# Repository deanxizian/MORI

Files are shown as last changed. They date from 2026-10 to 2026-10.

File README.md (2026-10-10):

# MORI

MORI 是一个两轮主动平衡机器人原型：两只轮驱舵机、头部偏航与俯仰两只舵机、圆形屏幕、真实摄像头及板载音频。

本仓库整理机械、硬件、软件、采购和验证资料。**当前为 PROTOTYPE / UNVALIDATED，未完成实物装配、上电和主动平衡验证，未制造放行。** 当前机械模型为 M1.55，已应用 C6 通道、CAM USB 朝右和用户批准的 R2 颈部装入修正，详见[本次更新](docs/M1_55_MODEL_UPDATE.md)。

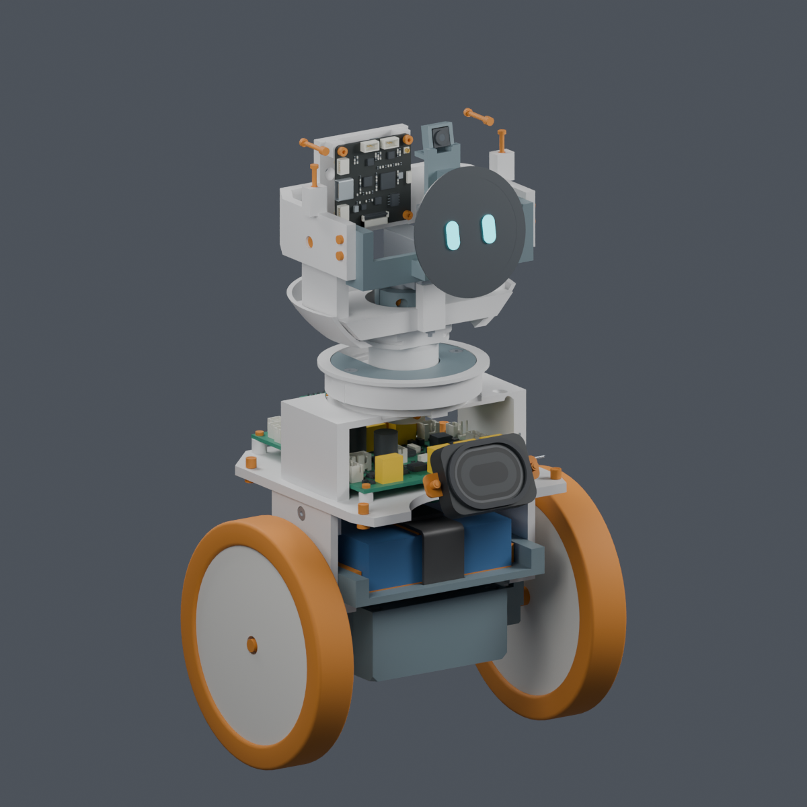
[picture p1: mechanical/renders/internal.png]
MORI 当前结构预览


首次归档的[拆分 PR 与审查修复](docs/REVIEW_STACK.md)已合并。历史与大批生成数据保留在不可变归档。

## 先看这些

| 要找的资料 | 入口 |
|---|---|
| 项目资料总索引 | [PROJECT_INDEX](docs/PROJECT_INDEX.md) |
| 当前版本与未完成事项 | [CURRENT_STATUS](docs/CURRENT_STATUS.md) |
| 到货前剩余工作与资料依赖 | [待补资料清单](docs/PREARRIVAL_BLOCKERS.md) · [未采用线束研究摘要](mechanical/studies/harness_M1_55_summary/index.html) |
| 从哪些厂家购买哪些产品 | [采购清单](mechanical/procurement/M1.52_按厂家采购清单_2026-10-06.md) · [已下单记录](mechanical/procurement/采购记录.md) |
| 机械模型、图册与装配视频 | [机械入口](mechanical/README.md) · [网页图册源文件](mechanical/index.html) · [装配视频](mechanical/animation/MORI_assembly.mp4) |
| 四块 PCB 的原生工程与接线 | [原生工程包与解压说明](hardware/v1_2/native_projects/README.md) · [P5R7 接线](hardware/v1_2/wiring_P5R7/README.md) |
| 网页、固件和模拟测试 | [软件说明](README_SOFTWARE_V1_2.md) · [原有验收记录](https://github.com/deanxizian/MORI/blob/48fe22aa75554c9d7bb237e2d2dcacca7f83dde1/reports/v1_2/acceptance.md) |
| 下载大文件、在本地打开图册 | [下载与归档说明](docs/GITHUB_ARCHIVE.md) |
| 历史版本和旧文件的适用范围 | [历史索引](docs/HISTORY.md) |

## 当前基线

当前资料整理日期：**2026-10-10**。规格为 [MORI_SPEC_V1_2.md](MORI_SPEC_V1_2.md)。

| 工作包 | 当前入口版本 | 说明 |
|---|---|---|
| 机械 | **V1.2-M1.55** | 主模型、电子细模和预览；当前 16 件机器人打印件，导出目录的 21 个 STL 还含其他试配文件 |
| 装配动画 | **V1.2-M1.55-A1** | 87.5 秒、22 步；裸打印件反力夹装入已修复，实际舵盘与完整带线装配仍未闭合 |
| 硬件合同 | **V1.2-H0.5-P5R7** | 运动板／后接口板 P5R7，电源板 P5R6，IMU 板 P5R4 |
| 软件 | **1.2.0-dev.1 历史交付记录** | 原验收日期 2026-09-22；不能据此声称已适配或验证后续 P5R7 硬件 |

硬件合同选择 WeAct STM32F412RET6 64Pin V1.1。2026-10-07 的审查修复已迁移默认编译目标并完成交叉编译，板级接通与实机验证仍未完成；详见[复核记录](docs/REVIEW_CLOSURE.md)。本次机械更新没有改动固件。

## 资料的有效范围

- 机械尺寸以 [config/geometry.json](config/geometry.json) 为当前唯一来源，安装契约为 [mechanical_interfaces.json](contracts/mechanical_interfaces.json)。单位 mm，+X 向右、+Y 向前、+Z 向上。
- 硬件选型以 [components.json](contracts/components.json) 为准；电气契约、原生 KiCad 板和正式交接各保留来源与版本。
- `mechanical/studies/` 同时包含已采用方案、未采用候选和失败试验。候选目录、截图或局部 PASS 不自动等于当前主模型。
- 根目录 `params.json`、`scripts/`、`models/`、`renders/`、`exports/` 属于 A0 历史。`hardware/v1/` 和旧软件台架记录也不是当前接线或尺寸依据。
- 几何检查、ERC／DRC、主机测试与仿真均不等于实物装配、热性能、材料强度、电池安全或平衡验证。

## 本地阅读

三个 Blender 工程采用 **Git LFS**；大型网格按需从不可变归档恢复，四套原生 KiCad 工程以 ZIP 保存完整文件，并保留可读的原理图与规则；工程包、视频、文档与源码使用普通 Git。克隆后先执行 `git lfs pull`，再按 [下载说明](docs/GITHUB_ARCHIVE.md)核对资产。GitHub 的 HTML 文件视图显示源代码；本地图册可这样打开：

```sh
python3 -m http.server 8000 --bind 127.0.0.1
```

浏览器打开 `http://127.0.0.1:8000/mechanical/index.html`；装配动画入口为 `/mechanical/animation/index.html`。这只启动静态资料服务，不启动控制程序。

旧软件 CI 配置保留在原始归档；这组资料 PR 没有新增自动构建或部署，也没有运行机器人或烧录固件。完整重建与历史对比的依赖边界见下载说明。

## 来源与许可

保留 [第三方通知](THIRD_PARTY_NOTICES.md)、[软件 V1.2 通知](software/THIRD_PARTY_V1_2.md)和 [机械来源说明](mechanical/THIRD_PARTY_NOTICES.md)。厂家文件与图片保留其原始来源和权利；公开仓库不改变第三方许可。本次没有为 MORI 自有内容另行指定开源许可证。

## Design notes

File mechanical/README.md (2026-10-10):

# MORI 当前机械资料

当前快照：V1.2-M1.55；装配动画：M1.55-A1。已采用 C6 通道、CAM USB 朝右和批准的 R2 颈部装入修正。相对 M1.54，只有 Pitch_Yoke 实体及其 STL 改变，其余 200 件原生零件和全部硬件位姿保持；不增加打印件或紧固件。主模型、电子细模、预览和动画已同步，详见[M1.55 更新](../docs/M1_55_MODEL_UPDATE.md)。完整线束未采用，PROTOTYPE / UNVALIDATED。

- [主模型](mori_v1_2.blend)、[电子细模](mori_electronics_detail.blend)、[动画工程](mori_assembly_animation.blend)：Git LFS。
- [21 个 STL](exports/)：含机器人本体打印件及其他试配文件，未制造放行。
- [视频](animation/MORI_assembly.mp4) · [视频页](animation/index.html) · [静态图册](index.html)。
- [构建与检查脚本](scripts/) · [几何源](../config/geometry.json)。
- [按厂家采购表](procurement/M1.52_按厂家采购清单_2026-10-06.md) · [已下单记录](procurement/采购记录.md) · [本次发布说明](../docs/M1_55_MODEL_UPDATE.md)。
- [未采用线束研究摘要](studies/harness_M1_55_summary/index.html) · [到货前待补资料](../docs/PREARRIVAL_BLOCKERS.md)。

直接打开当前 Blender 文件无需恢复历史数据。重新运行建模脚本前，应按 [归档说明](../docs/GITHUB_ARCHIVE.md)恢复源模型和生成网格，并准备原记录的 Blender／CAD Python 依赖。单个历史比较还可能依赖额外归档文件，不能跳过缺失项后声称检查通过。

头部最终传动配件、完整线束与实物验证仍未闭合，见 [当前状态](../docs/CURRENT_STATUS.md)。R2 裸打印件装入通过不代表实际舵盘或带线初装通过。

当前构建完成后运行 `python3 mechanical/scripts/report.py`，输出 `mechanical/current_report.html`。该命令校验当前输入与构建证据；不会用 M1.43 的报告模板覆盖当前版本，也不覆盖保留的图册。缺失或过期证据会返回非零退出码。

完整重建前先运行 `python3 tools/restore_archive_assets.py --group mechanical-build-inputs --group native-pcbs`，以及归档说明列出的厂家源输入，再运行 `python3 tools/restore_m1_55_evidence.py --group approval` 恢复 R2 比较输入。Blender Python 需要与其 ABI 匹配的 `manifold3d`；脚本记录实际安装版本。金属件导出直接使用 OCP（`cadquery-ocp`，本轮为 7.8.1.1），通过 `MORI_CAD_PYTHON=/path/to/python` 指定；缺失依赖时明确失败。`run_all.py --core` 完成当前构建、几何检查、渲染、STL/STEP 导出和报告刷新。R2 检查另保护了本地未发布的硬件候选快照；公开克隆没有这些快照时，完整来源保护重放会失败，不能跳过后声称全部检查已重现，详见[本次证据边界](../docs/M1_55_MODEL_UPDATE.md)。

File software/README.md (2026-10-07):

> **当前 MORI V1.2 入口：** [README_SOFTWARE_V1_2.md](../README_SOFTWARE_V1_2.md)。当前只开发网页，App 暂停。本页及原报告保留为HW-SW-0.4/A0台架记录，旧GPIO/电池阈值/PWM/CPR不适用V1.2。
> 固件源已原样迁移并增量适配到 `../firmware/motion/`，`firmware_work/firmware` 是兼容符号链接，没有第二份硬件固件。V1默认不初始化旧候选GPIO。

# MORI软件调试工程 SW-0.4

当前接口基准 **HW-SW-0.4 / 2026-09-21**，已依用户本次指令在现有工作副本上合并，模块台架候选，**PROTOTYPE / UNVALIDATED**。保留既有状态机、严格协议、模拟HAL、安装配置、表情/头轨迹和安全回归修复。没有连接、烧录或旋转真实设备；实物与自由平衡均 **NOT_TESTED**。

## 本次接口同步

轮电机候选改为Pololu #4863：48 CPR已含x4，精确减速比22³×23/(12×10³)，1:1候选皮带，979.616 counts/rev，Ø95轮每计数0.000304661522567m。运行时换算只定义于`mori_io.h`，设备INFO与模拟源共用配置；单边沿8帧测速、48边沿一电机转和元数据精度均有回归测试。GPIO、方向符号、IMU量程、保护阈值和默认安全门未改变。

编码器使用DEVKIT_5V供电，四条A/B经3.3V供电的SN74LVC14AD转换，禁止5V信号直入ESP32。USB前拔**整个J12逻辑降压线束，J14保持连接**；逻辑USB/外部5V互斥，禁Wi-Fi，含编码器预算<500mA。控制left对应Blender Wheel_R/Motor_R（X正）。VMAIN ADC不能覆盖可能被隔离的VM_MOTOR回灌尖峰，软件过压阈值保持8.65V。详细线序、钳位候选和限制见`docs/hw_sw_0_4.md`及调试手册。

本次接收的0.4快照23个成员均按manifest校验；基线在独立报告目录重新构建。最早从0.3解出的工作副本没有被覆盖，`baseline_integrity.json`保留原始追溯。旧发布报告归档到`reports/pre_hw04_merge/`；24个旧SIMULATED文件保留原内容和元数据，0.4演示另生成`SIMULATED_hw04_*`。此前接口兼容性FAIL的历史记录保留，其变更依据与解决结果见ICR-012、`reports/hw04_adoption.json`和当前`reports/final_validation.json`。

## 可运行入口

在`/Users/dean/Documents/MORI`执行：

```sh
# C主机回归、安全状态机、模拟HAL、严格协议及电机适配器（ASan + UBSan）
bash software/scripts/test_host.sh
# Python协议、采集/回放、模拟PTY串口、离线方向核验
python3 -m unittest discover -s software/tests -p 'test_*.py' -v
# ESP-IDF v5.5.2安全门关闭的默认配置构建，只build、不flash
bash software/scripts/idf_build.sh
# 校验仓库内附带的0.3/0.4 ZIP快照，不能代替当前代码或实机验证
python3 software/scripts/verify_delivery.py --archives-only
# 旧交付的完整审计需要另行恢复历史证据和当时构建产物；当前源文件已演进，可能报告差异
python3 tools/restore_archive_assets.py --group legacy-software-verification --group legacy-helpers
python3 software/scripts/verify_delivery.py
# 严格检查与本次已采纳0.4上游一致；不代表实物获准上电
python3 software/scripts/verify_delivery.py --require-current-handoff

# 无硬件演示：输出文件名必须含SIMULATED；换用新的文件名避免覆盖
bash software/scripts/build_simulator.sh
python3 software/tools/mori_cli.py simulate --frames 1000 --scenario estop --output software/reports/SIMULATED_demo_new.csv
python3 software/tools/mori_cli.py replay software/reports/SIMULATED_demo_new.csv
python3 software/tools/mori_cli.py validate 'move 0.02 0'
python3 software/tools/mori_cli.py fault 11
python3 software/tools/check_control_signs.py --output software/reports/SIMULATED_direction_new.json
software/reports/bin/SIMULATED_face 360 software/reports/SIMULATED_face_360_new.ppm
```

主机工具只用Python标准库和本地C编译器；串口使用POSIX termios（本次只在模拟PTY验证）。设备端仍用项目原dependencies.lock：ESP-IDF5.5.2、GC9A01 2.0.3、cmake_utilities0.5.3，未升级。`idf_build.sh`检查本地IDF tag严格等于v5.5.2。工作副本主机脚本指向software的安全包装；0.4上游基线另在reports中构建和运行，不执行hardware目录脚本。

真实串口须由用户以后明确提供端口再操作。采集只自动发info查询；`send --command`只发送显式提供的命令，支持多次`--command`完成有限台架脉冲。绝不自动发arm、confirm_signs、gains或ack，不自动重试/重连。ACK丢失是UNKNOWN，不推断执行失败，也不自动disarm。

## 目录与证据

- `firmware_work/firmware/`：以0.3ZIP为初始来源、已选择性合并0.4接口的独立ESP-IDF工程；portable `mori_core`、真实HAL、圆屏驱动。
- `firmware_work/pinmap.csv`及`wiring.csv`：0.4交接镜像，只读对照；GPIO未改。
- `tests/`：注入式时钟/传感器/执行器HAL、原问题回归、IDF LEDC契约stub和协议/工具测试。任意测试增益仅用于分支验证，不是实机调参数据。
- `tools/`：MORI/1串口采集、CSV回放、SIMULATED设备与表情渲染、方向/安装矩阵检查。
- `docs/debug_manual.md`：断电到低速运动的八阶段实物调试流程；`protocol.md`、`realtime.md`、`direction_checks.md`给出接口和测量口径。
- `config/`：实物记录及安装矩阵模板；未填项均NOT_TESTED/null。
- `interface_change_requests.md`：ICR-001..012，ICR-001旧电机提案已废止；ICR-012记录本次授权合并，其余安全/协议修复保留。
- `reports/`：真实命令/退出码/日志、快照与最终文件/镜像SHA、模拟CSV/JSONL/元数据；Git仓库不存在，Git状态NOT_APPLICABLE。

## 本次真实验证结果

- 修改后的C测试：2406条断言（163原始核心 + 2211模拟HAL/状态/协议/UI + 22电机适配器 + 10默认关门）及4项行为回归PASS，开启ASan/UBSan。
- Python：24项PASS，含5项HW-SW-0.4计数/8帧测速/元数据/接线验收，以及串口模拟PTY和严格协议/回放测试。
- ESP-IDF v5.5.2：默认关门、无屏、门内代码编译覆盖3种构建PASS；另在独立目录复现0.4上游基线构建及163断言PASS。
- 0.4模拟急停1000帧、复位400帧采集/回放PASS；旧版回放保留1204.44元数据，24个旧模拟文件哈希未变。
- 先前FAIL记录保留：0.4接口前置回归、主机测试中的float/double比较警告（已修正），以及构建路径纠正记录。当前结论/命令/退出码见`reports/final_validation.json`，源文件/产物SHA见`reports/delivery_manifest.json`。实物全部NOT_TESTED。

```sh
# 验证已生成的新旧版本模拟记录，无设备IO
python3 software/scripts/verify_hw04_recordings.py
# 读取0.4采集结果；不会将CSV重发为设备命令
python3 software/tools/mori_cli.py replay software/reports/SIMULATED_hw04_estop.csv
```

## 验证范围

| 功能 | 功能实现 | 单元/模拟或主机构建 | 实物验证 |
|---|---|---|---|
| HW-SW-0.4快照、接口同步、基线构建和163断言复现 | PASS | PASS | NOT_TESTED |
| DISARMED→CALIBRATING→READY→BENCH/BALANCE、锁存FAULT | PASS | PASS | NOT_TESTED |
| 默认关门/0增益、显式解锁、台架限幅/不续期、stop/断联语义 | PASS | PASS | NOT_TESTED |
| 故障注入：IMU旧/缺样、编码器跳变/冻结、ADC/NTC、过流/温/压、倾倒、饱和、nFAULT/急停、超时/溢出/复位 | PASS | PASS | NOT_TESTED |
| 严格MORI/1、ACK/REJECT、时间戳、回放、分位数/丢弃计数 | PASS | PASS | NOT_TESTED |
| 矩阵/正反号配置、速度外环→倾角→唯一公共姿态力矩 | PASS | PASS（符号关系，不是稳定性证明） | NOT_TESTED |
| 无屏/可变分辨率/圆形裁切/GC9A01 SPI后端 | PASS | PASS（编译/渲染） | NOT_TESTED |
| 头部限加速度轨迹与低优先级任务、未核验无PWM | PASS | PASS | NOT_TESTED |
| 1800us预算/健康帧心跳/分段测量钩子 | PASS | PASS（模拟超时与门控） | NOT_TESTED |
| 装机适配、真实电气/热/稳态/自由平衡/续航 | NOT_TESTED | NOT_APPLICABLE | NOT_TESTED |

本轮基线问题先记录FAIL，再修复并重跑：重复时间戳校准、首个故障被覆盖、READY失健康不锁存、额外命令字段被接受、提示词与快照的轮计数比例冲突、200ms台架截止晚一个帧、IDF同步LEDC更新缺少fade service初始化、BENCH输出覆盖低电告警。最终验证结果见`reports/final_validation.json`；历史FAIL日志保留用于复现，不伪装成硬件失败或抹除。

安全默认：POWER_STAGE_VERIFIED、ENABLE_BALANCE、HEAD_VERIFIED、AXES_VERIFIED均n，kp/kd/kv/ki全0。左右电机/编码器符号候选保持+1/−1；安装矩阵identity未验证。新增/修改接口必须走变更单。电池阈值保持6.8/6.6/6.0V及过压8.65V，不能代替BMS/保险/充电器/急停。屏幕240×240/Ø32.4mm仅编译与台架后端，最终Ø60屏仍未定。

## 追溯与再次构建

```sh
# 每次使用新的name，工具拒绝覆盖已有记录
python3 software/scripts/run_recorded.py --name local_build_01 -- bash software/scripts/idf_build.sh
python3 software/scripts/run_recorded.py --name SIMULATED_local_tests_01 -- bash software/scripts/test_host.sh
# 单独复现已封存HW-SW-0.4基线（报告区，不覆盖工作副本）
bash software/scripts/reproduce_hw04_baseline.sh
# 修改源文件后先完成验证，再更新交付哈希；不可用更新哈希掩盖检查失败
python3 software/scripts/fingerprint.py
python3 software/scripts/verify_delivery.py
```

`run_recorded.py`记录argv、cwd、UTC、返回码、完整输出及SHA；新记录也含运行前输入文件SHA。`baseline_integrity.json`保留最初0.3ZIP21个成员；`hw04_adoption.json`记录0.4ZIP23个成员、源文件和旧模拟文件SHA。默认镜像在`firmware_work/firmware/build/`。`build_variants.sh`只作无屏和门内代码编译覆盖；其`DO_NOT_FLASH_gated_coverage`镜像不具备实物签字，禁止用于台架出力。IDF自动输出的flash建议没有执行。

仍需硬件决定/提供：R矩阵与四个方向符号签字、真实皮带齿数/轮周长、功率安全链与母线回灌响应、最终电池/保护/充电路径、显示面板及总线、头中心/方向/行程/线缆、板卡和IMU外置或机械重排。仍需实测：所有通电/旋转/关断波形、传感器标定、时序最大值、负载干扰、扭矩/摩擦/惯量/热裕量及防摔下闭环表现。未完成这些项目，不宣称机器人已经能平衡。

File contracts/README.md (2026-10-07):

> 硬件候选已更新为 **V1.2-H0.2-P1**：[器件真值](components.json)、[电气真值](electrical_interfaces.json)。板间候选1Mbps，运动GPIO/DMA已按F412载板分配；实物资格未释放。MORI/2帧及软件profile仍由软件维护，本次未改协议源。

> S288专用CRC与下述CRC32不是同一算法。F413软件需按[硬件ADR](../reports/decisions/ADR-HW-V1_2-002.md)新增F412适配，不沿用A0的ESP32/PWM/2S接线。软件文档下文中“尚无引脚”的历史边界由电气契约更新，实际实时驱动接入仍归软件任务。

# MORI/2 软件契约 1.0

`command_spec.json` 是命令目录、参数类型、数值范围、权限、最长有效期的唯一软件定义。
`protocol.py` / `protocol.ts` 严格校验，`generate.py` 生成 JSON Schema 与嵌入式命令编号/数值校验；
`test_vectors.json` 在 Python 与 TS 跑同一批有效/无效样本。C 的数值子集另外做交叉 CRC 与属性测试。
机械值以 `mechanical_interfaces.json` 与 `../config/geometry.json` 为准，本目录软件协议不重定义孔位/器件尺寸。

## 命令与仲裁

一个消息只包含以下字段，额外/缺少字段、NaN/Inf、布尔冒充数字、范围溢出均拒绝。
原始 JSON 最大 4096 UTF-8 字节；后端额外拒绝重复 JSON 键、截断、非法 Unicode/递归对象。

```json
{"protocol":"MORI/2","device_id":"mori-sim-01","session_id":"从状态取得","command_id":"每个意图唯一ID","client_id":"配对返回ID","source":"console","permissions":["control"],"type":"SET_VELOCITY","params":{"v_m_s":0.1,"yaw_rad_s":0},"sequence":1,"sent_at_ms":100,"basis_device_ms":100,"valid_for_ms":300}
```

上例 ID 说明是占位文字，实际 ID 必须 `[a-zA-Z0-9_-]{1,64}`；不要照抄它发送。
`sent_at_ms` 只用于发送端日志，不用于跨机器时钟相减。`basis_device_ms` 必须回显最近状态的设备单调时钟；
设备按 `now - basis` 检查期限。因此旧状态不会因为网络重发获得新的300ms。
采集帧另带 frame_id、captured_ms、processed_ms、采集时头角/机身姿态；返回结果须匹配本机帧登记表。

命令目录含读取、显式解锁/人工维护、正常停止、故障禁驱、SI 速度、有限位移/转角、双轴头部、
表情、相机三模式、选目标、跟随/巡游/主动动作、取消、持久记忆 CRUD/导出/开关、音量、会话、按钮和唤醒配置。
详细参数和枚举以目录为准。ACK 表达明确结果状态，不等同动作完成：
ACCEPTED → RUNNING → COMPLETED / CANCELLED / EXPIRED / FAULT；格式/权限/门禁失败为 REJECTED。
有限动作的终态也发布在遥测事件中，控制台据此更新日志。

- 凭证权限在服务端决定；请求中的 permissions 只是所需权限，不能提升自己权限。
- 取得控制权须明确操作者看护；活跃租约由一个客户端持有，另一个会收到 CONTROL_OWNED。
- UI 前台每100ms续租，设备期限最多300ms；pointerup/cancel、blur、hidden、App inactive、断线停止续租。
- 断线撤销非零目标，健康平衡保持；重连不重放动作、不自动取得控制权或解锁。
- STOP_MOTION、FAULT_STOP 具有更高优先级，可用较旧序号停止，但仍需有效会话/权限/期限。
- 相同 command_id 不再次执行、也不续租；不同客户端撞 ID 被拒绝。每会话每客户端 sequence 单调。
- 交互/相机配置/记忆的认证独立于运动租约。头部、轮移动、解锁和自主模式必须持有运动租约。
- CANCEL 只取消当前匹配的动作，拒绝无匹配 ID；更换运动目标取消原目标。复位换 session 并禁驱。
- 模型/VLM/记忆内容是数据，没有 shell、原始 PWM、参数修改或公开相机工具。

## 两 MCU 二进制子契约

`wire.c/h` 与 `wire.py`：小端，`A5 5A | version=2:u8 | kind:u8 | payload_len:u16 |
sequence:u32 | MCU_boot_session:u64 | command_id:u64 | payload | CRC32:u32`。
CRC32 覆盖此前全部字节（IEEE/与 zlib.crc32 一致），最大 payload128、总帧158字节；不完整帧50ms丢弃。
版本/长度/零会话/零序号/零ID/CRC错误丢弃且计数。这里是本地电气损坏检测，**不是身份认证**。

运动子集 payload 固定前缀：`basis_device_ms:u64 + valid_for_ms:u16`，后接参数。
无参：READ_STATUS/HEARTBEAT/STOP_MOTION/RELEASE_CONTROL/FAULT_STOP；最后一个使用通用本地故障码。
布尔1字节且必须为1：CLAIM_CONTROL(监督确认)、ARM(本地确认)、DISARM/ACK_FAULT/ENTER_MAINTENANCE(支撑确认)。
两 float32 SI：SET_VELOCITY(v,yaw_rate)、HEAD_TARGET(yaw,pitch)。不支持的类型/长度明确 REJECTED。
网络端的人类原因/维护细节不会被任意透传为执行器字节。C 接收器把 legacy `MC_MOVE.b` 看作差动PWM，
故在未提供经过测量的 yaw-rate 控制器前拒绝非零 rad/s 请求，绝不按原增益直连。

`mori_v1` 已有可注入时间的解析/租约/禁驱/两轴轨迹测试；串口引脚、波特率、隔离、安全线、
完整状态回包与硬件四执行器 adapter 尚受 V1 硬件契约阻挡，默认固件不初始化任何候选 GPIO。
这不是可直接连接任意主控的接口承诺。上层自主状态机在同协议模拟器完整执行，实机门为 BLOCKED。

## 旧协议

MORI/1 和 HW-SW-0.4/0.5 台架 CSV 继续由 `software/tools/` 支持，原始日志不重标为 V1。
旧候选 GPIO、符号、979.616 counts/rev、母线阈值仅属于显式 A0.5 bench profile。
两协议不自动互转，不自动发 arm、confirm_signs、gains、ack。更改见软件接口变更单。

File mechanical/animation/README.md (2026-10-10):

# MORI 装配动画

MORI 装配动画 / V1.2-M1.55-A1

当前场景：MORI_Assembly_Animation。空格播放，Shift+左方向键回到开头。
总长 87.50 秒，24 fps，共 2100 帧。
时间轴的 22 个中文标记同时切换对应相机。每个零件保留独立物体与关键帧。
在 Outliner 按步骤展开集合；选零件，在 Dope Sheet / Graph Editor 调整时间。
原始 MORI_V1_Assembly 场景保留真实总装与运动轴，可切回检查尺寸。

身体改为前后两片外壳。承重桥在身体外壳未装时单独下放、前移并锁紧。
前壳喇叭和后壳接口板在台面分别预装；内部总成完成后，前壳沿-Y、后壳沿+Y合入。
底部两组一体插舌定位，四枚原框架螺钉经底部工具孔锁紧；旧拼缝螺钉和嵌件取消。
每片模块含原生附件的名义平移路径各检查275个位置，不含独立插头包络。
保存后的动画可另以半帧抽样；该项需单独的动画回读记录。
完整软线长度、变形和带线合壳仍未完成，动画未把静态导线示意当作装配证明。
双舵机先在离机座上锁紧；Pitch先在X+30mm处下放，再向左平移到位。
C压板先从侧面套到转动座，随驱动座一起下放。随后转动座转60°，
从上方锁两枚M3×8后回正，再安装俯仰头部。固定压板不随Yaw转动。
M1.49采用6806ZZ轴承（30×42×7mm）；压板配对孔位为X±26.2mm，
外径60.4mm。颈部11条局部导线空间检查不代表完整线束已完成。
拆卸需先移除俯仰头部，松开压板和反力连接后上提，不是整头快拆。
其他位移、台面预装与镜头切换仅作装配讲解。全动画的连续扫掠、人手／夹具、
完整软线束、紧固扭矩与真实零件公差仍未验证。头部舵盘／短轴仍未定型。
橙色表示未完整确认的部件；没有缩放采购件或改变候选 STL。

降压器区分：第6步的外置模块是轮驱9V（D36V50F9）和头部6V（D24V22F6）。
第7步电源板上的U60/U70已集成运动5V和CAM 5V；没有另装两块外置5V模块。
本视频采用V1.2-M1.55主模型，运动基板与后接口板已更新为P5R7；电源P5R6、IMU P5R4。
M1.54将CAM USB转向机器人右侧+X；CAM端相机FPC朝左-X，屏幕FPC朝下-Z。
M1.52仅把两枚现有反力连接试配螺母绕原孔轴转正30°，与六角槽方向一致。
M1.53将固定偏航桥左侧穿线口外边缘加宽0.8mm；轴承座和五金位置保持。
M1.55 R2 已应用裸反力轴从下方装入的步骤；保存后路径须通过独立回读。实发舵盘与最终锁紧叠层仍待到货核对。
槽口/触点仅为示意，真实插深、补强片和接触面仍未确认；完整线束尚未应用。
WeAct元件面朝上、排针朝下；先放三组排母，再插入核心板与E直排针候选。
E排针与原厂STEP孔径资料矛盾仍为BLOCKED，11.04mm是候选叠层，不能据动画确认实物配合或下单。

重新生成并回读验证（先成功生成当前主模型；R2 研究脚本可从 validation 资料包恢复）：

```sh
python mechanical/studies/reaction_clamp_R2_adoption/run_deliverables.py
```

[当前采用记录](../../docs/M1_55_MODEL_UPDATE.md)

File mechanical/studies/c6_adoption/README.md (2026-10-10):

> 这是 M1.53 采用时的历史检查记录；当前主模型已更新到 M1.54。当前结果见[发布说明](../../../docs/M1_54_MODEL_UPDATE.md)。

# C6 已应用 · V1.2-M1.53

用户确认后，将固定偏航桥 Yaw_Base 既有左侧穿线口外边缘向外加宽 0.8 mm。原外半径 11.7 mm → 12.5 mm，移除约 22.0474 mm³；不增加零件或紧固件。主模型、电子细模、21 个 STL、预览和 M1.53-A1 装配工程／完整视频已同步。

- 与审查后的 M1.52 原生几何逐件比较：只改变 Yaw_Base，其余 200 件保持。轴承座、孔轴、紧固件及所有硬件变换保持。
- 21 个导出件均通过闭合拓扑和 Blender STL 回导检查。机器人本体仍为 16 件打印件，其余是既有试配／支撑等输出。
- 九条历史下部线路对当前 201 个原生实体：1404 次分组有限姿态检查，均满足 0.3 mm 名义净距下界；采用前的槽口有 52 次不足。最近的实际查询样本下界约 0.3996 mm，但它不是所有路线的全局最小值。
- 身体前后模块各 275 个平移位置重新检查；保存后的动画回读还检查了分壳、防脱与舵机台架预装。原生实体之外的对插分配包络、软线和人手操作未据此放行。
- 全部既有硬件源文件与硬件合同哈希保持。该检查发生在本次 PR 发布之前。

完整线束仍为 BLOCKED：恒定材料长度、上端固定／应力释放、FFC／FPC 及带线闭壳等尚未完成。九条候选线路、滑动导线约束和回弯固定未随槽口一并采用。原有 WeAct 等资料问题仍单独保留，局部结果不是整机装配完成。PA12 配合、强度和疲劳 NOT_TESTED；manufacturing_release=false。

数值清理：新切口转存 float32 前以 1e-7 mm 简化容差去除四个退化三角形；与未简化实体的对称差约 1.09e-7 mm³。独立批准参考与保存后实体的差异另记于检查报告；这不是打印配合公差。升版时也保留了已审查的头前壳碎片清理。失败尝试日志保存在 attempt1/、attempt2/、attempt3/，没有跳过失败项。

[剖面对比](section_comparison.png) · [主模型](../../mori_v1_2.blend) · [Yaw_Base STL](../../exports/stl/Yaw_Base.stl) · [装配视频](../../animation/index.html) · [局部检查](review.json) · [范围检查](../../reports/neck_entry_relief_validation.json) · [当前整机检查](../../current_report.html)

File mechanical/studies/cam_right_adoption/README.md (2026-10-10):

# CAM USB 朝右已应用 · V1.2-M1.54

2026-10-08 用户批准“行，试试看usb朝右吧”。CAM 整板及板载两颗麦克风绕不变的板中心、世界 Y 轴转 -90°，USB 口朝机器人右侧 +X。正面对板观察时，机器人右侧位于画面左边。

相对 M1.53：只转动 CAM_Mainboard / Onboard_MIC_L / Onboard_MIC_R，另外 198 件的原生实体与可见网格逐件保持；所有 21 个 STL 文件的 SHA256 完全相同。板框、中心、32.6 mm 四孔轴集合、原固定座、螺钉、相机模组与 LCD 不变，不增加打印件。全部既有硬件源文件和 components.json 保持。

当前主模型、电子细模、预览和 M1.54-A1 装配动画／完整 MP4 已同步。视频仍为 22 步、85.75 秒、1280×720、24 fps。当前 core 检查为 26 PASS / 0 FAIL / 9 NOT_TESTED / 11 BLOCKED，后两类没有被此次局部通过覆盖。

## 已检查的范围

- 当前 201 个原生零件的静态、130 个组合头姿态、拓扑、光学和主要进出路径检查；原 WeAct 源模型孔针问题仍单列 BLOCKED。
- 10×5×12、10×5×16、11.2×6.7×17.5 mm 三种 USB 本体**设计预留**，130 个姿态下达到 0.3 mm 名义净距；不是已采购完整插头或实测插合尺寸。
- 四枚原 CAM 螺钉的 12 条工具／螺钉扫掠，及下述连续纯平移安装路径。动画另按半帧读取了 471 个可见 CAM 零件姿态，没有检出与当时可见原生零件的穿插。
- 两个板载麦克风从左右排列转为上下排列，原 L/R 名称保留源通道身份。共享头腔到既有声孔的名义空隙探针通过；未增加声学导管或新孔。声音定位、声学和 RF 性能仍需实测。

## 安装顺序

显示架和头壳后装，CAM 四枚螺钉尚未锁紧：板卡向前 +Y 错开 2 mm 从上方下放；离最终位置尚高 8 mm 时从右侧 +X 预接 USB；再下降 8 mm、向后贴回 2 mm，锁原来的四枚 DIN912 M2×5。动画展示该板卡路径；未添加虚构的成品 USB 插头。

## 走线交接

CAM 侧相机 FPC 出口 +Z → -X；屏幕 FPC 出口 -X → -Z；LCD 和相机模组一端保持。旧 M1.53 上端走线与长度结果只对旧方向成立，不能直接用作当前路线或供应商裁线图。信号、电源、喇叭上端及 FPC/FFC 必须重新组织并联合复核。此前下部线路也未随本次转向被自动放行。

完整插头／尾线型号、CC 源端、真实插合深度、排线触点面／长度、应力释放、带线闭壳和舵盘最终叠层仍未完成。没有扩大此次改动范围。全部模型依旧 PROTOTYPE / UNVALIDATED，physical_validation=NOT_TESTED，full_harness=BLOCKED，manufacturing_release=false。

[当前预览](index.html) · [主模型](../../mori_v1_2.blend) · [视频](../../animation/index.html) · [范围检查](../../reports/cam_orientation_validation.json) · [接口检查](../../reports/cam_right_service_validation.json) · [实际命令](commands.json)

2026-10-08 PR 同步复核：构建与全部衍生文件已按当前代码重新生成。动画回读先刷新隐藏验证集合，避免屏幕碰撞体使用旧矩阵；完整命令及日志见[执行证据包](execution_evidence.zip)，发布结果见[交付复核](../../../docs/review_evidence/M1_54_publication.json)。

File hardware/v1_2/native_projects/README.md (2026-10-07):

# 当前原生 KiCad 工程

四套完整工程按原生文件打包，来源为固定提交 `48fe22aa75554c9d7bb237e2d2dcacca7f83dde1`。运动／后接口 P5R7、电源 P5R6、IMU P5R4；没有改变尺寸、走线、符号或封装，也不代表制造放行。

| 工程 | 完整文件包 |
|---|---|
| 运动载板 P5R7 | [MORI_motion_P5R7.zip](MORI_motion_P5R7.zip) |
| 电源板 P5R6 | [MORI_power_P5R6.zip](MORI_power_P5R6.zip) |
| IMU 板 P5R4 | [MORI_imu_P5R4.zip](MORI_imu_P5R4.zip) |
| 后接口板 P5R7 | [MORI_rear_P5R7.zip](MORI_rear_P5R7.zip) |

原理图、设计规则、项目配置、接线表和说明仍在 `../kicad/` 以原生文本提供。PCB 与封装的完整序列化内容位于上述 ZIP；它们的行数超过 GitHub diff 上限，Git 属性不能阻止该接口展开这些文本。ZIP 使用普通 Git，不使用 LFS。每个包包含该工程的全部本地文件和配套库，供解压后直接在 KiCad 中检查。

在仓库根目录执行以下命令，`-n` 保留已有文件：

```sh
unzip -n hardware/v1_2/native_projects/MORI_motion_P5R7.zip -d .
unzip -n hardware/v1_2/native_projects/MORI_power_P5R6.zip -d .
unzip -n hardware/v1_2/native_projects/MORI_imu_P5R4.zip -d .
unzip -n hardware/v1_2/native_projects/MORI_rear_P5R7.zip -d .
```

然后从 `hardware/v1_2/kicad/MORI_*/` 打开对应 `.kicad_pro`。ZIP 内已带完整的仓库相对路径；无需重新缩放或移动 PCB。若本地已有修改，先保留并自行比较，不要覆盖。

[manifest.json](manifest.json) 记录每个 ZIP 及全部 242 个原始文件的 SHA256。2026-10-07 仅更新 connectivity/layout_notes/rule_mapping 的元数据；PCB、原理图、规则和配套库字节与原始归档一致。位置从包内实际 PCB 重新提取；这不是重新布线或制造验证。完整历史、旧方案和硬件验证记录仍在原始归档，不因本次打包获得重新验证。

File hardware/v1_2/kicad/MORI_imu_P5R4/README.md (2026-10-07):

# MORI_imu_P5R4

V1.2-H0.5-P5R4 / PROTOTYPE / 实物 NOT_TESTED。

本版保留 P5 电路、元件和针号；修改摆位、局部布线、IMU 专用 Paste 与轴向丝印。详见 [审查处理记录](../../layout_P5R4/README.md)。

外形与安装接口不变。PCB 不是制造释放文件；没有台架、ESD、温升或整机装配合格声明。

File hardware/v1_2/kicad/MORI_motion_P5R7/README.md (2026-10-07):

# MORI motion P5R7 — WeAct 插合修正原型

WeAct 元件面朝上，A–E 全部排针从核心板背面向下；载板 A–D 孔位与所有针号/网络分配保持。E 的 8 个孔相对 P5R6 整体 X+2.54 mm，Y 不变；新版项目使用独立修正版封装。载板仍只连接 E7/NRST，E 其余孔未接入载板电路。无需另接复位飞线。

|孔|原生 X mm|原生 Y mm|核心板信号|载板连接|
|---|---:|---:|---|---|
|E1|34.93|19.28|GND|NC|
|E2|37.47|19.28|GND|NC|
|E3|34.93|21.82|PA10|NC|
|E4|37.47|21.82|PA14/SWCLK|NC|
|E5|34.93|24.36|PA9|NC|
|E6|37.47|24.36|PA13/SWDIO|NC|
|E7|34.93|26.90|NRST|NRST → D1.1|
|E8|37.47|26.90|3V3|NC|

排母候选为 Würth 61303021821×2、61300821821×1；E 向下直针候选为 61300821121。排母本体高8.5 mm、焊脚长3.1 mm来自厂家图；完整插合高度、接触插深与保持力未验证。核心板的原厂 STEP 含 E 弯针，不能只旋转整个模型就当作上述装配。机械需替换排针装配姿态，并复核核心板上方空间、上下焊脚、维护/插拔路径。优先采购未焊针版本或要求按确认方向装配；不要把已焊弯针版本当作直接插合件。

70×35 mm 板框和安装孔保持。R19 从 (33,16) mm、−90° 改为 (32,16.575) mm、0°；R9 保持方向，下移3.25 mm至 (45,17) mm，打开中部走线/换层通道；其余器件位置保持。E 排母的实际本体投影另设两面布线约束，只有 E7 自身的直向逃线通道；没有 GND/电源的通用豁免。相关复位、反馈、按键、状态和 IMU 信号局部重布；另按实际 A–D 排母投影调整保留的 S288 总线及采样信号，滤波元件、接口功能和供电拓扑保持；新线0.20 mm，新过孔0.80/0.30 mm。原 P5R6 和原设计规则完整保留；新增规则限制 E 和 A–D 排母下的非自身走线；自身引脚逃线另作逐条复核。

PROTOTYPE / 实物 NOT_TESTED。完整原生检查、局部走线审查、68针位置表及新裸板 STEP 见 [本次交接记录](../../reviews/weact_E_J3_20260930/README.md)。机械空间仍需按正确朝向重新集成验证，没有下单或生产释放。

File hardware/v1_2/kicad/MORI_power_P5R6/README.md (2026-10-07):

# MORI_power_P5R6

V1.2-H0.5-P5R6 / PROTOTYPE / 实物 NOT_TESTED。

本版保留 P5 电路、元件和针号；运动板修正 BAT54H 焊盘；电源板缩短自举回路、并联 SW 过孔及消除 M5_EN 直角；电源/后板补充实际接口丝印。IMU 保留 P5R4。详见 [审查处理记录](../../layout_P5R6/README.md)。

外形与安装接口不变。PCB 不是制造释放文件；没有台架、ESD、温升或整机装配合格声明。

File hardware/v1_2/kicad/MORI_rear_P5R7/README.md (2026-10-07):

# MORI rear P5R7 — J3 装配修正原型

J3 保留 JST B4B-PH-K-S(LF)(SN) / PHR-4 / SPH-002T-P0.5S，改为 B.Cu 安装、180°，向下插拔。1 号孔为原生板坐标 (14.45,21.20) mm，孔排整体 Y+1.70 mm。原生顶视图从左到右为 4、3、2、1；各编号对应的网络和线束功能不变。

|针|网络|对端|
|---|---|---|
|1|MASTER_RETURN|电源板 J19.1|
|2|GND|电源板 J19.2|
|3|LOOP_3V3|运动板 J8.1|
|4|CLR_N|运动板 J8.2|

板框仍为原生 24×25×1.6 mm；安装孔、其余器件坐标、原理图拓扑均保持。P5R6 文件完整保留。不要在旧 P5R6 板上仅把插座翻面；P5R7 已调整编号孔位的网络连接。

三根互锁信号局部重布；0.20 mm 线宽、0.80/0.30 mm 新增过孔。J3 的塑料本体投影按 JST 图中 9.9×4.5 mm 确定，不把 Fab 层外侧的 1 脚 L 形标记算入实体；原有逐引脚逃线通道保留，无新增 DRC 忽略。

PROTOTYPE / NOT_TESTED。检查、几何局限和带哈希交接见 hardware/v1_2/reviews/weact_E_J3_20260930/README.md。SW1 电路本次保留；整机物理断电/急停实现另需闭合。没有下单或生产验证声明。

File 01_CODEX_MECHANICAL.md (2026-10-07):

# 提示词 1｜MORI V1.2 外观优化、内部结构与 Blender 装配

请实际改进并制作 MORI 的 Blender 工程。目标是“简洁好看、真实可装配、方便维护”，不是再出概念海报，也不是只把旧的丑模型换灯光。

## 0. 先读取与执行

先读本包 `MORI_SPEC_V1_2.md`、`AGENTS_MORI_TEMPLATE.md`、`04_HANDOFF_AND_ACCEPTANCE.md`、`REFERENCES.md`，再读现有仓库AGENTS、Blender模型/脚本、硬件BOM和共享接口。

检查Blender/Python/已有MCP。以Blender+bpy脚本为主，可用MCP辅助，不把MCP当开工前提。
保留已有可用零件与无关文件，先给一个简短实施计划，再实际改模、运行、检查。
没有.blend时按规格生成；没有Blender执行环境时交付可运行脚本与阻塞说明，不能伪造渲染或检查通过。

任务结果写入 `mechanical/`；拥有 `config/geometry.json`、`contracts/mechanical_interfaces.json`。只读取硬件任务拥有的 `contracts/components.json`，新增需求用ADR协商。
已有同用途参数文件时迁移/兼容，不能新旧脚本各读一份相互矛盾的参数。

## 1. 紧凑需求摘要

- 正常高度≤300mm；暖白圆润头身、圆形黑脸、仅双眼、隐藏双轴头、两只纯色车轮；不加轮毂灯环。
- 四电机：S288轮驱×2、SCS0009头部×2。无运行第三轮。
- 交互为微雪CAM-OV3660 SKU33700、1.85圆屏SKU35079、板载双麦和身体内扬声器。
- 运动为STM32小板+身体IMU；3S候选电池、电源板、USB-C充电口和至少一个实体功能按钮。
- 预算≤1000元尚未验证。采用FDM能做的分件、现成紧固件和平面面罩，不要求昂贵曲面玻璃、整件金属加工或喷涂才能成立。
- 用户已允许有限偏离正球形；不要因旧提示词而坚持把头/body切成不协调的球形方盒。

## 2. 先解决外形，不把结构孔洞到处摆出来

从当前实渲染定位问题，至少检查：

1. **身体轮廓**：正视图不应因左右过深平切而变成直侧板箱体。保留肩部到腹部的连续圆润收分，不用巨大平圆片/夸张轮眉盖住轮位。
2. **头部轮廓**：侧面不再用过大的整块切平让头看起来像戴平面头盔；圆屏窗口为局部需求，周围球面/柔和过渡保持自然。
3. **脸部比例**：显示有效区域45.68mm量级，以原厂图复核；面罩可更大但不能整块都画成能发光的屏幕。摄像头在有效区外的真实透光窗，优先融入黑色面罩，不增加一个巨大的额头洞。
4. **轮子**：适度内收，纯暖白轮盖+深灰胎；不外露长轴，不让轮胎卡进壳体，不因隐藏轴承造成不可拆。
5. **头身连接**：隐藏短转盘/支架，控制中立与俯仰时的缝隙；不是把完整头球与实心身体顶板互相穿模。
6. **细节**：分件线、按钮、USB-C、声孔分组布置。正面不堆螺钉、灯条和随意散落的小孔；不让分件缝穿过喇叭孔阵列造成脆弱边缘。

先用同一参数化构造，真实建模两套外形：
A. 接近双球、局部柔和过渡；B. 更丰满且略收腹的圆润卵形身体配近球头。
头轮比例、显示有效尺寸和内部包络一致，不靠不同透视作弊。
给出前/侧/45°对比，按空间、重心、分件和美感选择一套主线继续，不做十种空泛概念也不强制等待确认才推进。

## 3. 参数与几何基准

先读取 `seeds/geometry_seed.json`，若已有可信的新参数，以实际文件为准并记录差异。
起点：头120mm、身160mm、轮径95mm、轮宽18～20mm、离地25mm、轮壳目标4mm、壳厚2.4mm；正常高度目标285～295mm。
这些不能全部独立硬锁：总高由实际外形、截切、轴线、间隙求得；完整运动最高点另测。

X向右/Y向前/Z向上；轮轴沿X。头yaw正向左，pitch正向抬头。保留构造基准、原始母体、轴线与安装面。

- 轮轴高度=实际胎外半径。
- 球形基线身体球心高度=母球半径+实际腹部离地；采用非球修形时由实际最低点计算，不能继续套球公式。
- 轮子内侧位置由真实侧面/截切、轴承座和间隙决定，不独立拖轮子。
- 对160mm身体/95mm轮径/25mm离地/2.4mm壳厚的球基线，轮轴高度附近内腔直径仅约104mm。此值只提示窄截面风险，不是可用矩形板框或验证结果。
- 不能让两只电机、联轴器与横放电池在同一狭窄截面相互占据空间。

镜头、板卡、屏幕数据缺失时，显示为有尺寸与状态的保守包络。未知真实外形不得通过非等比缩放“装进去”。

## 4. 双轴头部：按真实运动链设计

优先布局：身体顶部yaw驱动与承重转盘 → 转动支架 → 头内pitch两侧支撑 → 头壳/屏幕/相机/CAM板。
明确每件属于身体固定、yaw-only或yaw+pitch运动组，质量与惯量按组统计。

- 只采购两只SCS0009及必要接口，不塞一整套StackChan方形主机。
- 两轴尽量通过头球中心或靠近真实重心。yaw承重环/轴承与pitch双侧支撑分担载荷，避免细舵机轴单侧悬挂整个头。
- 建立电机本体、安装耳、输出端、舵盘、螺钉、线束与支架；只有盒形舵机占位不算完成连接。
- 检查原厂可提供的安装尺寸。SCS0009名义本体23.2×12.1×25.25mm不包含所有安装外廓，不能据此冻结孔距。
- 头内优先容纳微雪CAM整板，DVP/QSPI尽量短且留在同一运动组；相机FPC不得随意延长。出现冲突需列替代布局和电气风险。
- 微雪板载麦克风有真实声孔/短声道，天线避开大面积金属与电池；接口可以插拔，不能被pitch轴穿过。
- 跨关节只走必要电源、通信及扬声器线，分开高噪声线与信号，设置服务环、应力释放和最小弯曲半径的待验证值。
- 不用滑环，不无限旋转；yaw±60°/pitch -20°～+25°作为预审范围，必要时缩小并同步软件契约。
- 头活动件目标150～200g。由体积、材料和采购件质量计算，不把空壳质量冒充整头质量。
- 俯仰重力矩按实测/估计重心偏移计算，舵机回差、线缆力和动态惯量交给硬件任务复核；不能只按堵转扭矩判够用。

## 5. 身体内部：承重、维护、声学一起考虑

- 2×S288主体20×34×26mm按原厂图核验；建立输出连接与可靠锁紧。
- 轮载通过框架、短轴和轴承传递。原厂未给轴端径向/冲击允许值时，不能直接让舵机输出端承受全部轮载。
- 不加额外FOC电调占位；S288已有内部驱动。半双工接口和运动板仍需保留。
- 电池中部可有限调位；初始电池安装限制包络80×65×30mm只是预算空间，不代表真实3S电池已选定。
- STM32装机板板框目标≤70×50mm；台架开发板与最终载板分别建模，尺寸无法达到应报告，不缩放元件。
- 身体前侧放扬声器与可拆小音腔；后侧放电源/控制板、按钮与USB-C，保持合适维修可达性。
- 身体IMU与刚性框架可靠连接，不在响腔、松动壳盖或头部上。
- 电池避开热源与锐边，固定不压迫软包，留插头拔出、固定带和检修路径。
- 声孔不与结构关键薄壁/分件缝重叠，不把麦克风和喇叭放入未经验证的共同声腔。
- 电源口按实际USB-C模块厚度、插头外壳和应力设计。调试SWD/UART可藏在维修区，不把一个USB口想象为所有板同时可刷机。

## 6. 分件与打印

至少独立管理：头前后壳、面罩、屏幕框、相机座、yaw/pitch机构、身体壳件、承重框架、电机座/轮轴件、轮毂/胎/盖、电池托架、板卡支架、声腔、按钮/接口件、紧固件、外置停放托架。
标记 PRINTABLE / PURCHASED_REFERENCE / PLACEHOLDER；数据状态与验证状态分开。

选择有定位特征和可维护螺钉的结构。公差、嵌件孔、轴承孔先做小样；不笼统宣称某个0.3mm间隙适合所有FDM。
面罩优先平面黑色切片/现成窗口，镜头区域需真实透光，不强制昂贵曲面玻璃或镀膜。
轮胎采用实际软质采购/制造方案，不把硬PLA轮当成已验证抓地轮胎。
不将轴承、PCB或电池混入可打印STL。原始模型与打印摆放、爆炸位移分别保存。

## 7. 必须实际执行的检查

构建可重复的 `build.py`、`validate.py`、`render.py`、`export.py`，或沿用已有等效脚本。只清理本项目命名空间；连续运行不重复堆对象。

检查并报告：
- 正常总高、宽深、腹部最低点、所有非轮部件离地，轮轴与左右轮同轴关系。
- 轮子360°旋转的实际最小间隙；转向/俯仰姿态下的可能壳体接地。
- yaw/pitch联合姿态网格与极限组合；身体俯仰±15°只作几何检查，不宣称安全运行区。
- 屏幕、CAM板、镜头、舵机耳、支架、紧固件、排线包络的实际干涉。AABB只能初筛；需三角网格/距离检查或明确未验证。
- 遮光框是否遮挡屏幕实际发光区，相机视场是否被窗口或运动件遮挡。
- USB插拔、所有螺钉工具路径、板卡与电池装拆顺序。不能有“大零件必须穿过小孔才能装配”的步骤。
- 导出网格闭合性、法线、非流形边、退化面、自交风险、关键壁厚。缺算法就标NOT_TESTED，不随意吞掉错误。
- 候选STL回读后的单位/尺寸/零件数，确认无1000倍缩放与爆炸位移残留。
- 分运动组质量与惯量、头部重心和整机重心，列假设和缺失数据。
- 外置托架在维护禁驱条件下的支撑，不把托架站稳当纯双轮断电自立。

有限姿态采样不是连续空间保证。线束柔性只做保守包络时必须说明，需要实物弯折/耐久测试。

## 8. 交付与阶段完成定义

M1：真实参数化两套外形对比、选定主线、初步内部包络与缺失尺寸清单。
M2：真实器件回写、接口/孔位/转轴、剖视、完整动作包络、重量预算。
M3：候选分件、试打小样、可拆装说明、真实渲染与报告。

至少输出：
- `mechanical/mori_v1_2.blend`、脚本与构建说明。
- 正/侧/后/顶/底正交图、45°图、头部剖视、身体内部、爆炸图、离地与间隙标注图。
- `mechanical/exports/` 中通过相应检查的候选打印件。
- `contracts/mechanical_interfaces.json`、更新后的geometry参数和质量/惯量表。
- `reports/mechanical_v1_2.md`：已完成、实测依据、未确认件、干涉与下一步。

所有交付渲染来自同一真实模型；必要缺陷不能靠后期修图抹掉。原厂尺寸不完整时完成M1和可完成部分，M2接口不得伪冻结。
现在先检查文件，按M1→M2→M3推进当前可完成的工作。

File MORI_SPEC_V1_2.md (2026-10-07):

# MORI V1.2｜共同产品规格与当前工程基线

日期：2026-09-22。
优先级：用户后续明确要求 > 本规格 > 三份任务提示词 > 旧提示词/旧参数 > 概念图片。
本规格冻结“要做什么”和当前主选；**不代表器件接口、动力、成本、装配或安全已验证。**

## 1. 用户需求：三个任务都必须保留

| 项目 | 要求 |
|---|---|
| 用途 | 个人陪伴机器人；拟公开源码与制作资料，未来可能销售 |
| 预算 | 首台装机材料、必要模块、一次基础 PCB 打样、打印材料、连接件及国内运费合计≤1000元；工具、人工、现有服务器与云 API 运行费另列 |
| 尺寸 | 正常装配高度≤300mm，优先把可用头部动作也控制在300mm内；完整姿态包络单独报告 |
| 外观 | 极简暖白/白色、深灰轮胎、纯色轮毂；圆润头部、饱满身体、无明显长脖子；允许为美感与装配有限偏离数学正球 |
| 轮子 | 两轮主动平衡、无运行时第三支撑；轮子适度内收但不得夹壳，腹部有清楚可测的离地空间 |
| 执行器 | 4个：左/右轮各1，头部yaw/pitch各1；无机械roll、活动嘴或手臂 |
| 显示 | 圆形，纯黑底，bloub/Grok Bot风格双眼；不显示白底黑球、轨道、粒子；不增加嘴 |
| 视觉 | 摄像头必需；可关闭、按需拍照/识物、持续选定目标跟踪 |
| 行为 | 手动/语音指令移动、主动短距离活动、视觉跟随、有限巡游；全在开发范围，但各模式按证据分别启用 |
| 场地 | V1只在清场、平整、坚硬室内地面；不要求地毯、门槛、楼梯或桌面自由移动 |
| 保护传感器 | 不加专用测距、避障、防跌落传感器；保留平衡IMU、执行器反馈与电源/故障监测 |
| 语音 | 第一版中文，唤醒词为主，有实体按钮备用；不要求特定音色/性格，不用Grok原生语音 |
| 名称 | MORI；“你好，Mori/莫里”是期望唤醒词，实际离线模型需验证，不把字符串配置当实现 |
| 操作 | 语音、App、网页、至少一个可达功能按钮；维护和严重故障的物理电源/禁驱操作明确 |
| 云端 | 用户已有腾讯云服务器；配置、带宽、地域、GPU未知；先生成部署文件，不默认获准远程更改服务 |
| 记忆 | 真实持久化长期记忆；跨重启，支持查看、纠正、删除、导出和关闭 |
| 续航 | 至少60分钟目标，按持续平衡+显示+摄像头跟踪+间断聊天/移动的混合工况验收 |
| 充电 | V1外部USB-C有线充电、无触点自动回充；使用无电机的外置托架，维护时不自由移动 |

## 2. 主选硬件与证据边界

来源编号见 `REFERENCES.md`；板卡后缀、生产批次、尺寸图和实际采购页必须再核查。

| 功能 | 主选/候选 | 当前边界 |
|---|---|---|
| 两轮执行器 | Unitree YS-342026-S288 ×2 | 连续旋转、集成驱动；0.6N·m是带工况说明的最大/堵转标注，不是连续额定能力 [S01] |
| S288通信 | 独立6Mbps、8N1、半双工TTL总线 | UART时钟、收发电平、方向释放、报文/CRC和超时行为都要验证 [S01,S02] |
| 运动MCU | 优先STM32F413RGT6或同系列适配板 | 宇树例程仅作起点；具体板型未冻结，必须实算UART误差、核验资源和体积；不盲目照抄寄存器 |
| 身体IMU | TDK ICM-42688-P，SPI+数据就绪 | 模块与电平/安装尚待核实；刚性固定在身体，不随头转 [S07] |
| 头部执行器 | FEETECH SCS0009 ×2 | 参考StackChan双轴；独立于S288总线，6V支路；真实反馈、孔耳和版本待核查 [S03] |
| 交互板/摄像头 | Waveshare ESP32-S3-CAM-OV3660，SKU33700 | 板载双麦、音频电路；板框、连接器高度、相机FPC长度和可用UART待核验 [S04] |
| 圆屏 | Waveshare 1.85inch Touch LCD Module，SKU35079 | 360×360、ST77916、QSPI；显示区45.68×45.68mm，产品外形55×55mm；整套厚度、接插件和实际圆形边界按图 [S05] |
| 音频 | 复用微雪板载ES7210/ES8311/NS4150B与双麦；配套4Ω3W扬声器 | 不重复计入独立麦克风/Codec/功放；声学和扬声器外形待验证 [S04] |
| 电池 | 成品3S、2200～2600mAh候选 | 化学体系、保护/均衡/温度、尺寸、持续电流未冻结；不焊接裸电芯 |
| 电源 | 受保护的轮驱电源、独立6V头部支路、5V逻辑/交互支路及各板本地稳压 | 3S满电12.6V与S288允许上限相接，无过压余量；必须解决回灌、容差及瞬态，不可无条件直供 |
| 充电 | USB-C输入+匹配3S的成熟充电/保护方案，后续集成载板 | PD触发器不等于充电器；BMS不替代CC/CV；原2S/BQ25887不可沿用 [S08] |

“宇树控制板”尚无具体型号：USB通信转接板不是平衡主控。保留这个待核查项，不凭空补全为成品运动控制器。

## 3. 机械布局起点（可调整，不是全部独立锁死）

- 头部名义母球直径120mm；身体名义母球直径160mm。
- 轮胎外径95mm，宽18～20mm；腹部离地目标25mm（初期允许20～25mm评估）。
- 轮壳目标最小间隙4mm；工程预审目标下限3mm，不代替公差/变形验证。
- 主体壳厚起点2.4mm，可分区薄壁和局部加强；实际打印规则以材料与设备验证。
- 头部yaw ±60°，pitch -20°～+25°，角度范围可为避让缩小；不无限旋转、不加滑环。
- 正常总高目标285～295mm，≤300mm为产品上限。球心、截切、转轴、总高需由实际几何联立求出，不能各自硬填。
- 整机质量工程目标约1.0～1.2kg；大于目标需重新做动力预算，不意味着1.2或1.5kg是已证实承重极限。
- 俯仰运动件质量目标150～200g，重心尽量靠近pitch轴；两只舵机的动态负载均需计算。

布局优先：屏幕、相机、CAM主板放头内；pitch支架与舵机位于头内/接合区；yaw舵机与承重转盘放身体顶部。电池、STM32、IMU、电源与扬声器放身体。

若CAM整板与双轴结构冲突，先调整支架和板姿态、有限修形；不能把高速DVP/QSPI排线任意加长、折死或跨轴无约束摆动来“解决”。改变放置位置需要记录信号与线缆代价。

## 4. 用户放宽形态后的审美规则

头120/身160是空间基准，不是让机器人变成“两个截过头的球和两个轮子”。允许克制的卵形/球面过渡与局部削切，保持圆润整体感。

必须改善上一版实渲染的问题：身体像竖直侧板箱体；头部脸面大切平；轮子离壳/露轴突兀；分件线和孔洞到处可见；头身接合生硬；脸屏与头比例不协调。

不通过删相机、删声孔、堵USB口、做全封闭不可拆外壳来换取“简洁”。相机可藏在黑面罩内但必须在屏幕有效区之外有真实透光窗。

生成式参考图不规定真实结构、尺寸或器件长相；图中的轮毂灯环、前额重复相机、巨大发光面和装饰灯不进入默认BOM。

## 5. 软件与接口

- 运动控制：独立STM32工程，参考Hover控制结构，重新适配S288与MORI动力学；SCS0009头控不能阻塞平衡。
- 交互：微雪ESP32-S3，显示/相机/音频实际例程打底，按版本审查后接小智与ESP-SR。
- 表情：只移植bloub双眼，保留电脑端确定性预览；嵌入式C/C++与LVGL，不在MCU运行Vue。
- 后端：腾讯云上的小智兼容服务端最小部署，ASR/LLM/TTS/VLM可替换；无需Grok原生语音或Pipecat/LiveKit/TEN全套。
- 客户端：Vue3+TypeScript+Vite一个控制台，Capacitor生成App工程，PWA不能单独充当原生App交付。
- 长期记忆：有来源、时间、用户/设备边界的持久化；敏感信息与人脸模板不默认积累；连续音视频默认不永久留存。
- 板间默认有帧边界/长度/版本/序号/CRC/心跳/命令租约的本地UART。具体速率在GPIO/布线核查后确定；不另加CAN收发器只为“更专业”。
- S288总线、SCS0009总线、板间UART分开；TTL的协议、电平、波特率分别核验。
- MCU不同SDK版本可以共存，但契约必须相同；外部SDK按commit/tag锁定，不盲目使用latest。

## 6. 运动安全与可用性

没有移动保护传感器，V1不是可靠避障或无人值守导航产品。跟随/巡游全部开发，但只在人工看护、清场、无台阶且无儿童宠物进入的场地解锁测试。

- `STOP_MOTION`：取消移动目标；健康状态下减速并继续平衡。
- `FAULT_STOP/DISARM`：经核验的禁驱或故障策略，可能倒下。不能把S288某个mode值想当然当成自由卸力。
- 通信丢失、交互MCU重启：撤销主动位移，不永久保持最后一个非零命令；健康运动域独立运行。
- 严重IMU/执行器/电源故障：保护优先，锁定故障，不能保证继续站立，不自动反复上力。
- 上电默认不ARM；自检及明确解锁后才运行；维护、刷机、复位、充电、关机在托架/人工可靠支撑下完成。
- 语音和Web不是唯一急停；功能按钮与可直接操作的电源/禁驱职责分开。
- 没有托架检测器时，“在托架内”只能是人工确认，不能自动宣称传感器已确认。
- 初始自主测试限速0.10m/s、单段0.30m；租约300ms、跟踪观测年龄250ms仅为待测起点，不是安全认证值，也不能用它粗暴截断平衡纠偏输出。

## 7. 三个任务共用的真值源

项目已有同用途文件时兼容迁移，不同时创建旧params.json与新geometry.json而各读各的。

- `config/geometry.json`：结构任务负责。几何目标、单位、装配位姿和运动范围。
- `contracts/components.json`：硬件负责。型号/板修订、原厂尺寸、重量、图纸、缺失项及数据状态。
- `contracts/mechanical_interfaces.json`：结构负责，硬件审核。坐标、板框、孔位、安装面、排线和插头净空。
- `contracts/electrical_interfaces.json`：硬件负责。电源轨、电平、连接器、总线、GPIO和默认状态。
- `contracts/protocol.*`：软件负责，另两任务审核。通信、命令/状态、数据单位、故障语义。
- `reports/decisions/`：ADR变更记录。任何跨域变更都要列出对方需更新的文件。

数据状态：`ASSUMED` / `VENDOR_DOCUMENTED` / `MEASURED`；装配、兼容、性能另有验证状态，不能因为原厂给了尺寸就标整个零件“验证通过”。

种子数据在 `seeds/`，只是建立共享文件的起点。无数据填null，不填0或任意假值；未知器件可用带标记的限制包络继续设计，不能冻结最终孔位。

## 8. 坐标、时间与证据

机械坐标：X向右、Y向前、Z向上，右手系；轮轴沿X。yaw正向左转；head pitch正向抬头。
软件用m/s/rad；机械用mm，界面显示deg需显式转换。机身前倾正方向由运动契约定义；不可把它与头pitch或IMU裸轴直接混用。

相机图像坐标、光轴、机身IMU、头关节都定义变换。状态带采集时间和年龄，不能把不同MCU/服务器未经同步的绝对时钟直接相减。

验收分层 DOCUMENT / GEOMETRY / HOST_TEST / SIMULATION / BENCH / ROBOT；结论 PASS / FAIL / NOT_TESTED / BLOCKED / NOT_APPLICABLE。
没有执行日志不写“测试通过”。有限离散干涉采样不等同连续运动证明，模拟一小时不等同真实续航。

## 9. 预算与决策门槛

1000元没有被用户放宽。之前约1287元是部分海外价格折算+未核实预留的情景计算，不能当国内采购报价，也不能用它自动改成1500元预算。

国内候选BOM需列规格、数量、单价、日期、税运口径、链接和是否真实现货；不自动使用学生价、首单价、批量价，不假定未声明的配件“已有”。

预算关键项缺价或总额>1000元时：继续完成参数化模型、可替换接口、原理预研与模拟软件，但暂停采购批准/PCB制造冻结；输出差额和最小改动提案，未经同意不删功能、不换主路线、不超额下单。

安全电源、必要线束与轴承不能为凑预算记零。一次打样和返工余量分列，计划≤900元留100元是愿望，不是已实现报价。

## 10. 60分钟验收与发布范围

定义并记录：持续平衡与黑底双眼，摄像头轻量跟踪开启；累计10分钟低速移动、累计10分钟语音交互、每分钟一次小幅头部动作。亮度、音量、处理模式、温度、电流、电压和结束电量完整记录。

安全清场/外部保护条件与可能改变动力学的支撑需记录。托架静置续航不能替代自由平衡混合工况。

代码/硬件/模型素材分别核查许可。宇树通信代码可能有非商业条件；bloub代码许可不等于xAI形象许可；不得把所有文件一律改标MIT。未来销售是可能性，不是已获授权的承诺。

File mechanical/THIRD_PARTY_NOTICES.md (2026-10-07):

# 来源与第三方说明

- 主规格：用户附件，已原样存入 `../MORI_SPEC_V1.md`；未从参考图片描摹外壳。新增 MORI 几何由本项目 bpy 脚本构造，未导入 StackChan、Hover、bloub 的 CAD、代码、图像、字体或角色素材。眼睛是程序生成的两个简单圆角图形，不声称 xAI / Grok 的授权或联名。
- Manifold 3.5.3：随附 `scripts/vendor/` 的 macOS ARM64 扩展用于实体布尔。许可证为 **Apache-2.0**，原文与 AUTHORS 保留在 `manifold3d-3.5.3.dist-info/licenses/`。来源：https://github.com/elalish/manifold 。二进制源自本机此前项目已安装依赖，本次记录版本与散列；未重新编译或认证其全部上游依赖。
- Blender 5.2.1 LTS：本机已安装应用，未随包分发。bpy API 与 Blender 内置 Python / NumPy 用于建模和数值计算；Blender 许可证说明：https://www.blender.org/about/license/ 。版本、构建 hash 与实际日志在 reports 中。
- StackChan 的双轴分工仅作为架构参考：[官方 case README](https://github.com/stack-chan/stack-chan/blob/develop/case/README.md)。查阅于 2026-09-21，未复制其文件，不对未来引用其他文件的许可证作概括授权。
- 打印材料的通用参考：[Prusa PETG](https://help.prusa3d.com/article/petg_2059)、[Prusa 柔性材料](https://help.prusa3d.com/article/flexible-materials_2057)，查阅于 2026-09-21。材料指南不验证本模型的强度、轮胎抓地、摩擦或疲劳。
- MORI 自身开源许可证仍由用户决定；本次未代用户声明整个项目可按某一商业许可证分发。旧 A0 的 hardware/software 源与许可保留，需由各自工作包继续逐文件核验。

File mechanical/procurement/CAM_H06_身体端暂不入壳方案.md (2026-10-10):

# CAM H06：身体端先压接、装机后入壳

2026-10-08 · **用户已确认交付形态；端子选型、尺寸与制造仍未批准**

用户确认：“接受厂家压接、装机后入壳”。本次只闭合身体端暂不入壳、装机后四个端子入壳的装配选择，不覆盖后文尚未完成的尺寸、工艺与路径验证。

目的：保留 CAM 与运动板之间的四芯信号连接，让身体端能够逐根穿过小通道；不用在机器人内部现场压接。

## 建议交付形态

1. 厂家完成两端压接和检查。CAM 端按最终确认的配对件装好插头；身体端的四个端子先不插入 `PHR-4` 塑壳。
2. 四条线分别标记 **H06-1、H06-2、H06-3、H06-4**，保护并分开放置身体端的端子；`PHR-4` 塑壳随线交付。保护方法及保护后最大外形仍需校核，不能直接把热缩管厚度忽略。
3. 装机时，在头壳与相关光学件尚未安装的阶段，依次完成穿线。不能靠拉扯卡舌、修剪端子或强塞来通过通道。
4. 穿线后按已核对的孔号把四个端子插入身体端塑壳，确认锁止并逐针导通。随后插到运动板 J5，完成固定和后续装配。

这会增加 **四个端子入壳** 的手工步骤；不增加打印件或螺钉，也不要求用户现场压接。暂不把这份方案当作已经通过的完整装配顺序。

## 保持的电气定义

| 标签 | 运动板 | CAM 板 | 信号 |
|---|---|---|---|
| H06-1 | J5.1 | J11.1 | CAM_RX |
| H06-2 | J5.2 | J11.2 | CAM_TX |
| H06-3 | J5.3 | J11.3 | CAM_3V3，仅作 U4 VCCB 参考 |
| H06-4 | J5.4 | J11.4 | GND |

来源：现行 `hardware/v1_2/wiring_P5R7/03_逐针接线表.csv` 的 H06 四行。RX/TX 以 CAM 端命名，不再交叉。表中的号码不是观看线端时的左右顺序；实际塑壳孔号视图、线色和 CAM 配对型号必须另行核对。

## 尚未闭合的条件

- 正式交接仍列 `SPH-002T-P0.5S`；细线研究组合是 `Alpha 2841/7 + SPH-004T-P0.5S / SSH-003T-P0.2-H`，**没有替换正式选型**。此方案的用户确认只涉及交付形态，不批准端子或线材替代。
- JST 公共目录中的 PH 单端子 5.7 / 2.08 / 1.5 mm 不是此线材压接后的完整包络。卡舌、压接桶、毛刺、切断端和保护套的最大尺寸仍待得到。
- 四根容量参考线逐根穿入的名义连续检查已完成，真实线材/压接件、初始理线、最终成形、后装 USB 供电线和闭壳尚未通过；当前候选总长不能下发为裁线尺寸。
- 本次确认不授权询价、发送供应商消息、采购或制造；未改变主模型或任何硬件文件。

## 可查来源

M1.54 历史容量复核记录见 [CAM H06 引用资料](../../docs/H06_REFERENCE_RECORDS.md#terminal)。早期检查只覆盖 2.28 × 1.7 × 6.7 mm 容量盒的刚性路径和导向口短段；后续四根逐根穿入与让位已补齐，见下文。容量盒仍不是选定端子的压接后尺寸，实际端子和全流程不放行制造。

R2 第一阶段完成第一根 CAM_4 从上入口到颈部下出口的带线连续几何检查，下段覆盖 4,168 个连续区间，上方 R7 松线弯另行检查。后续仍沿用这个上下段连续、有限弯线跨度的基线，不继承不同临时线形的装入结论。研究线径没有替代正式线材，不下发裁线尺寸，不把候选导向／固定结构应用到主模型。

该历史容量研究中，**四根带线逐根穿入的连续候选通过**，顺序为 CAM_4 → CAM_3 → CAM_2 → CAM_1。前三根依次连续让位（258、130、128 个区间），第三根另有 4 个临时 S 段抬升区间；最后一根使用另一侧松线弯。第四根完整端子路径 3,045 个区间、松线弯 440 个扫掠单元、下段活动线 4,168 个连续区间通过，独立数值和源文件核对通过。仍未完成初始理线／头托移入当前形态、最终整理、身体端入壳与闭壳。第三根暂放段数值最小几何半径约 1.466 mm；线材允许值、线径公差和真实压接保护外形尚未冻结。研究线径没有替代正式 PH AWG28；不能下发制造或裁线长度。完整数值报告及独立核对已打包，见同一资料页。

**最新材料对照修正**：上述 PASS 只针对机械零位的容量几何。Alpha 2841/7 官方外径 0.6096±0.0508 mm、弯曲半径为线径 10 倍，按最大外径需 R6.604 mm；当前送入阶段约 R2.990 mm、第三根临时让位约 R1.466 mm，因此这个参考线材组合标为 **FAIL**，不能下发。它还是 AWG30，且低于正式 PH002 的绝缘夹持下限；没有更换正式 AWG28/PH002。详见[材料对照](../../docs/H06_REFERENCE_RECORDS.md#material)和[入壳资料要求](../../docs/H06_REFERENCE_RECORDS.md#housing)。

**较缓 AWG28 参考，仍未采用**：已独立核对 Alpha ThermoThin 2628 当前 5 倍外径版本，并将首根候选入口直段及尾部过渡跨度延长。按未说明的半径基准保守换算为中心线 R4.0513 mm，首根下部 1,314 个连续区间、固定下部基线和解析上入口曲率通过；这不覆盖完整原厂尾线或其他三根的全过程。其均匀最大外径 0.7366 mm 在当前 1 mm 接口出口中心距下只有 0.2634 mm 表面间隙，低于 0.3 mm 目标，故整束仍 **BLOCKED**，不是已发现实物相撞。该参考需要 PH004，正式 PH002 与厂配 SH 尾线定义未改；镀镍导体压接工艺、供货版本和实际尾线仍待核对。详见[独立 AWG28 研究](../../docs/H06_REFERENCE_RECORDS.md#awg28)。

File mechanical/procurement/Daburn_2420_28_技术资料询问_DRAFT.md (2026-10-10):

# Daburn 2420/28 技术资料询问稿

状态：DRAFT / NOT_SENT。未选用该线材，未授权发送、询价确认或采购。

收件人候选：daburn@daburn.com。
依据：[Daburn 官方联系页](https://www.daburn.com/contact-us.aspx)，2026-10-10 读取。
不使用页面中疑似拼写错误的另一地址。

现有资料：[2420 产品页](https://www.daburn.com/2420-Ultra-Flexible-Microminiature-FEP-Lead-Wire.aspx)
与 [Revision D 规格书](https://www.daburn.com/specs/2420_Spec_Sheet_04-29-2013.pdf)。
标称外径不是最大外径，厂商的柔软描述不是已给出的数值弯折要求。
此稿不涉及用户已决定到货后处理的飞特舵盘或微雪 FPC／FFC。

Subject: Technical data request for 2420/28: OD tolerance, bending and crimping

Hello Daburn Technical Support,

We are evaluating 2420/28 for a small robotic prototype with finite yaw and
pitch motion. It has not been selected or ordered. We have read your product
page and Revision D data sheet, which list AWG28, 65/46 bare-copper stranding
and a nominal insulated diameter of 0.022 inch / 0.559 mm.

Could you please provide the following product-specific information?

1. Guaranteed minimum and maximum insulated outside diameter, and the
   applicable tolerance and measurement method for 2420/28.
2. Minimum bend radii for installation, static service and repeated flexing;
   please identify whether each radius is measured at the wire centreline
   or the inside of the bend. If no rated minimum is available, please say so.
3. Any existing repeated-flex test data: radius, motion, cycles, temperature,
   sample construction and acceptance criteria. We are not treating a general
   flexibility description as a qualification for our application.
4. Available guidance for crimping the 65/46 fine-stranded conductor into
   small open-barrel contacts, including any restrictions or product-specific
   test evidence. The proposed contacts remain subject to their manufacturers'
   requirements and separate crimp validation.
5. Whether short sample lengths can be supplied for engineering evaluation,
   and the available lengths, colours and price basis. This is an information
   request, not a purchase order.

Our current, unqualified geometric allocation has a maximum insulated wire
diameter of 0.6604 mm in one head section. Its model checks do not qualify wire
material, connectors, crimps or installation bending. We would use your
guaranteed data to decide whether the allocation needs to be revised.

Thank you.

## 回复接收后仍需处理

- 保留原始回复、附件、日期与文件哈希；按字段接收，不把回复摘要当作整件资格。
- 将线材公差、安装／工作弯折要求带入完整路线与带线装配检查。
- 实际 CAM 配对、JST 端子选择、压接外形及夹持资格单独核对；不得修改电路侧文件。
- 只有实际端接和固定位置明确后，才计算裁线与工艺余量。

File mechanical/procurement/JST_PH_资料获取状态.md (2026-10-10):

# JST PH 资料获取状态

2026-10-10，机械资料核对；不是选型变更或制造放行。

正式运动基板 P5R7 的 J5 沿用 B4B-PH-K-S(LF)(SN)，H06 身体端仍为 PHR-4 与 SPH-002T-P0.5S。没有改成细线 PH004、其他系列或高盒版本。

## 已核对的公开入口

- [JST France PH 产品页](https://www.jst.fr/fr/produit/ph_159?search=PHR)包含 PHR-4 型号和公开目录入口。
- [France PH 目录](https://www.jst.fr/core/file.get?path=doc%2Fjst%2Ffamily%2Fpdf%2Feph0125.pdf)有外形、配对系列与端子线规表，未补齐实际压接后外形、内腔、第一可弯点、完整插入行程及操作空间。
- [JST France 下载页](https://www.jst.fr/fr/telechargement-n380)没有本次所需的 PH 专用装配说明链接。
- [JST UK PH 产品页](https://jst.co.uk/productSeries.php?pid=163)确有 Handling Manual 入口。该入口实际转到日本 JST 的资料登记页，文件参数为 CHM-1-105.pdf 与 CHM-1-2201.pdf；尚未收到或读到这两份文件，不推断其具体内容。
- [手册登记入口](https://www.jst-mfg.com/product/index.php?doc=11&filename=CHM-1-105.pdf%7CCHM-1-2201.pdf&series=199&type=10)要求公司、部门、姓名、地址、电话、邮箱，并接受使用条款后由邮件接收资料。没有填写或提交，没有接受协议，也没有取得这些受限文件。
- [日本 JST PH 产品页](https://www.jst-mfg.com/product/index.php?series=199)列出了 PHR-4、B4B-PH-K-S 和 PH002 的独立 CAD／图纸入口；本次没有取得详细 CAD。
- [JST America PH 产品页](https://www.jst.com/products/crimp-style-connectors-wire-to-board-type/ph-connector/)在此次普通浏览器观察中仍显示自动安全验证；没有执行验证码操作或绕过验证。网络读取返回 403。

## 尚未闭合

已保存的公开 JST 通用手册只支持一般的余量、握壳插拔和线材／端子匹配要求。它不能证明“先把空 PHR-4 插在板上，再逐针装入端子”的 PH 专用工序可行，也没有证据说明该工序一定禁止。该方法保持 BLOCKED。

需要匹配本型号的内腔／锁止几何、压接后外形及装配说明，才能完成逐针入壳、带线插合和手／工具操作空间复核。公开外形容量检查及先前裸端子路径通过不代替这些要求。

喇叭插头尺寸等用户到公司后提供。已确认的壳体出口至现有插头末端 150 mm 保留，不能当作 150 mm 可自由弯折的裸线。

本次资料查询未消除四组完整线束工作的依赖：完整路线、材料与实际线长、端接与应力释放、带线装配与闭壳。主模型、打印件、硬件源、动画和装配顺序均未改变；没有发送厂家消息、新提交或推送。

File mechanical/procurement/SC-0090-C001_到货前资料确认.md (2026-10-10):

# 已购 SC-0090-C001：到货前接口资料

> 2026-10-08 用户决定：即将到货，先不索取这些资料，待实物到货后核对并调整。本稿保留备查，尚未发送。

2026-10-08。用户已确认购买 **SC-0090-C001 / SCS0009 单轴版**，待收货。该完整型号输入已闭合，不再要求订单链接来识别型号。项目使用两只；实际订单数量、随附配件和批次尚无独立记录。

本文件是可转发的资料询问草稿，尚未发送给卖家或厂家，不是订货或加工要求。正式采购记录见[采购记录](采购记录.md)，型号证据见[确认记录](evidence/2026-10-08_SC-0090-C001_confirmation.json)。

## 给订单卖家的简短询问

您好，我已购买 SC-0090-C001（SCS0009 单轴版），正在设计与原配舵盘连接的结构。请帮忙确认这批货：

1. 输出花键是 20 齿还是 25 齿？飞特官网正文和参数表不一致，请以这批实发型号为准，并提供对应规格书版本。
2. 包含哪些舵盘和中心螺钉？请提供舵盘正反面照片及尺寸图，尤其是外径、总厚度、安装孔距/孔径、花键啮合深度，以及装好后的轴向尺寸。
3. 中心锁紧螺钉的规格、允许旋入深度是多少？原厂尾线是否随货，是否另含分线板？请发配件清单或整套照片。

如果这些资料需要厂家提供，请协助转询。请勿用 SC-0090-C013 双轴版、SC09 或其他型号的图纸代替。

## 厂家需要补齐的详细字段

收到上述基本回复后，以下字段仍用于完成结构和线束图；未提供的继续标为未知：

| 接口 | 需要的原始资料 | 影响 |
|---|---|---|
| 产品批次 | SC-0090-C001 的对应规格书修订；本体 23.2/23.3 mm 文字与外形图差异的解释 | 本体/安装基准是否需更新 |
| 舵盘 | 料号、正反面尺寸、中心承压面、孔位、花键孔、实际插入深度及装配剖面 | 两轴传动短轴与连接盘定型 |
| 中心螺钉 | 原配型号、头部尺寸、有效螺纹深度、允许旋入量和推荐扭矩 | 轴向锁紧；不能仅凭旧资料的 M2×4 放行 |
| 尾线 | 出线坐标/方向、线规、绝缘外径、150 mm 长度基准与公差、线根直段和弯曲限制 | 动态线束长度与应力释放 |
| 接插件 | “5264-3P”完整制造商料号、配对件及端子图；编号必须注明插合面/线尾视角 | 线束供应商对接和极性 |
| 分线附件 | 是否随货；若有，提供料号、外形、固定孔和插头完整尺寸 | 头内固定与可拆装空间 |

A/0 第 4 页的端子表和第 8 页接线示例存在编号方向疑点，需要厂家给出同一视角的编号图，不能靠线色或照片猜接线。

## 来源与处理边界

- [飞特产品页](https://www.feetechrc.com/6v-23kg-serial-bus-steering-gear_65522.html)：同页关联 SC-0090-C001 与 SCS0009。当前已保存的规格书为 A/0、2020-11-23；下载路径中的上传日期不是产品修订。
- [原厂规格书下载](https://www.feetechrc.com/Data/feetechrc/upload/file/20260622/6391771873533994748433885.pdf)：本地文件和 SHA256 在型号确认记录中。花键、附件矛盾尚未消除。
- [飞特售后服务页](https://www.feetechrc.com/after-sales-service-and-policy)：2026-10-08 核对官方邮箱为 `aaron@feetechrc.com.cn`。仅记录联系方式，未发送消息。

收到文件后，先核对 SKU/修订/单位/来源，逐字段更新来源记录，再复核原尺寸模型、轴向叠层、传动连接及装入路径。涉及孔位或结构变化时提供具体候选确认。没有厂家回复或实物记录的尺寸不改成“已确认”，也不以其他型号的舵盘替代。

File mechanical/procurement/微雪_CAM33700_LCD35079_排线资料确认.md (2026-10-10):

# 微雪已购两件：排线与连接器资料询问稿

> 2026-10-08 用户决定：即将到货，先不索取这些资料，待实物到货后核对并调整。本稿保留备查，尚未发送。

2026-10-08。已购 **ESP32-S3-CAM-OV3660（SKU 33700）** 和 **1.85inch Touch LCD Module（SKU 35079）**，各一套、待收货。型号与购买进度已确认，不重复索取订单链接来识别产品。

以下是可转发给订单客服或微雪技术支持的草稿，**尚未发送**。不包含订货、加工或电路修改要求。

## 可直接转发

您好，我已购买 ESP32-S3-CAM-OV3660（33700）和 1.85inch Touch LCD Module（35079），正在设计机器人内部安装。相机镜头与 CAM 板分开放置，需要核对原配软排线能否连接。官网板卡尺寸、原理图和屏幕 STEP 已查看，还请提供这批产品对应的以下资料：

1. **原配 OV3660 相机总成的尺寸图**：请包含传感器／镜头座、整片 FPC 展开轮廓、各段宽度和厚度、有效自由长度、两端补强／不可弯区域，以及允许弯曲半径。请同时标明插入端和 1 脚方向。若原配不可分离、不可延长，或需专用延长配件，也请说明；如有兼容配件，请提供其完整型号和图纸。
2. **三个排线座的完整厂家料号和装配图**：CAM 板的 24P CAMERA 座、18P DISPLAY 座，以及屏幕上的 18P 座。需要插槽相对 PCB 的位置／高度、适配 FPC 厚度、插入深度、接触面及锁扣打开所需空间。请以本次实发板卡版本为准，注明版本。
3. **随屏附带的 18P 排线规格**：完整料号、展开长度、宽度／厚度、两端裸铜及补强长度、两端接触面关系和允许弯曲半径。请用明确的插合面示意说明 1 脚对应，便于与两个插座匹配。

如果没有 STEP，带尺寸的 PDF／DXF 或原厂连接器图纸也可以；若某个字段无法提供，请注明，便于到货后针对性复核。请勿以其他 OV3660 模组或 ESP32-S3-Touch-LCD-1.85 一体板的图纸替代。

## 这些资料具体解决什么

| 缺失资料 | 目前已知 | 需要闭合的工作 |
|---|---|---|
| 原配 OV3660 完整 FPC | 官方装机照片中露出的窄段约 6–7 mm，属于照片估算；隐藏扇出和全长未知 | 判断原配是否够长，确定真实外形与弯折，不把任意矩形带当成原配线 |
| CAM 相机座实际槽位 | 当前模型只有照片重建的封装，不能把封装中点当接触平面 | 避开 SD 卡座，确定真实出口和装入／锁扣空间 |
| CAM／LCD 屏幕座及 18P 成品排线 | 官方电气定义已收到；LCD 16–18 为 NC 已在硬件 A2 记录 | 确定插合、补强及折弯，完成完整路线和带线装配 |

当前模型中相机与 CAM 接口的包围盒中心距离不是排线长度；不把它写成订制线长，也不依据未知插槽高度要求厂家制造或挪动插座。针序、供电和兼容性仍由硬件任务确认。

## 已核对的官方入口

- [CAM 产品说明](https://docs.waveshare.com/ESP32-S3-CAM-OVxxxx)：SKU 33700 对应 OV3660 套装。
- [CAM 资源页](https://docs.waveshare.com/ESP32-S3-CAM-OVxxxx/Resources-And-Documents)：2026-10-08 查到原理图及相关芯片资料；本页未列出上述完整相机 FPC 和连接器机械图。不能据此断言厂家没有这些资料。
- [LCD 产品页](https://www.waveshare.com/catalog/product/view/id/8439/s/1.85inch-touch-lcd-module/category/346/)：对应已购的独立屏幕模块。
- [CAM 技术支持入口](https://docs.waveshare.com/ESP32-S3-CAM-OVxxxx/Technical-Support)链接至[微雪工单系统](https://service.waveshare.com/)；仅核对入口，没有提交工单。

来源照片及尺寸基准见相机 FPC 照片与基准复核（本地研究：`mechanical/studies/harness_current_M1_54/cam_fpc_photo_review/`）。实物复核保持 **NOT_TESTED**，完整排线和制造放行保持 **BLOCKED**。

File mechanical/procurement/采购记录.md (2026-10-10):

# MORI 采购记录

本表持续记录用户确认的采购进度；待购买项目见 [按厂家采购清单](M1.52_按厂家采购清单_2026-10-06.md)。

## 2026-10-07：微雪 Waveshare 成品模块

用户确认：“这两个我现在已经下单了。”下单日期按本次确认日期记录（北京时间），两款各 1 套。

| 产品 | 微雪 SKU | 数量 | 单价（CNY） | 小计（CNY） | 采购进度 | 官方产品／采购入口 |
|---|---|---:|---:|---:|---|---|
| 1.85inch Touch LCD Module，1.85 英寸圆形触摸屏，360×360 | 35079 | 1 套 | ¥99.99 | ¥99.99 | 已下单（用户确认） | [微雪 LCD 产品页](https://www.waveshare.com/catalog/product/view/id/8439/s/1.85inch-touch-lcd-module/category/346/) |
| ESP32-S3-CAM-OV3660，摄像头开发板套装 | 33700 | 1 套 | ¥109.08 | ¥109.08 | 已下单（用户确认） | [微雪 CAM 系列购买页](https://www.waveshare.com/product/arduino/boards-kits/esp32-s3-cam-ov5640.htm)，选 With OV3660 camera／33700 |
| **商品合计** | — | **2 套** | — | **¥209.07** | **未含运费** | — |

### 金额与链接依据

- 价格和数量取自用户提供的 [购物车原始截图](evidence/2026-10-07_waveshare_cart.png)，金额为截图商品价，不是官网当前报价或已核验的订单实付金额。
- 采购进度来自用户确认；实际订单 URL、订单号、运费、优惠和最终实付金额未提供。表内记录的是对应型号的官方产品／采购入口，不冒充用户的订单链接。
- CAM 系列页面 URL 含 OV5640，所记录的下单型号为 **OV3660／33700**；型号与 SKU 对应关系见 [微雪官方说明](https://docs.waveshare.com/ESP32-S3-CAM-OVxxxx)。
- 这是本次两项商品的已知金额，不是整机采购总价。

### 到货状态

两项收货均待用户确认，实物复核状态为 **NOT_TESTED**。到货时核对实发型号、板卡修订与附件；屏幕的 18P FFC／15P 连接线及 CAM 的原配 OV3660 相机和排线随实物一起记录。采购进度不改变现有机械配合、排线走线与装配验证结论。

2026-10-08 已整理[排线与连接器资料询问稿](微雪_CAM33700_LCD35079_排线资料确认.md)，用于在到货前索取对应相机完整 FPC、三处插座及随屏 18P 排线的原始图纸；尚未向商家或厂家发送，不是新增采购。

## 2026-10-07：WeAct 运动主控选型确认

用户确认：“OK，那还是保留 WeAct F412 吧。”继续沿用 **WeAct STM32F4 64Pin CoreBoard V1.1／STM32F412RET6，1 块**。本次 F413 成品板比较未形成替换决定；现有基板、安装接口和模型不因这次确认而变更。

- 采购进度：用户随后确认 **已下单、待收货**，见下方本次下单记录。成交链接、价格、实发修订与附件待记录；官方入口见 [按厂家采购清单](M1.52_按厂家采购清单_2026-10-06.md)。
- 适配进度：F412 编译目标与内存布局已调整，并有交叉编译通过记录；实际时钟、GPIO、UART／DMA 等板级驱动仍待接通，6 Mbps 实物通信为 **NOT_TESTED**，E 接口插合仍为 **BLOCKED**。选型确认不等于兼容性实测通过，见 [当前状态](../../docs/CURRENT_STATUS.md)。

## 2026-10-07：舵机、调试板与 WeAct 下单确认

用户确认：“OK，头部舵机、轮子舵机及它们的调试板都买了，然后 WeAct F412 也买了，等收货。”本节日期为用户确认日期；尚未收到订单明细。

| 项目 | 对应选型 | 项目配置数量 | 采购进度 | 成交价格／订单链接 |
|---|---|---:|---|---|
| 头部舵机 | 飞特 **SC-0090-C001／SCS0009，单轴版本**，偏航／俯仰各 1 个 | 2 个 | 已下单、待收货；2026-10-08 用户确认完整商品型号 | 未提供 |
| 轮子舵机 | 宇树 YS-342026-S288，左右轮各 1 个 | 2 个 | 已下单、待收货（用户确认） | 未提供 |
| 头部舵机调试板 | 前述推荐为飞特 FE-URT-1，使用 SCS 的 TTL 单总线端 | 1 块，共用 | 已购买该类调试板、待收货；具体型号待核对 | 未提供 |
| 轮子舵机调试板 | 前述推荐为宇树 S288／J288 单总线串口转 USB 模块 | 1 块，共用 | 已购买该类调试板、待收货；具体型号待核对 | 未提供 |
| 运动主控板 | WeAct STM32F4 64Pin CoreBoard V1.1／STM32F412RET6 | 1 块 | 已下单、待收货（用户确认） | 未提供 |

- 表中数量沿用此前单机与台架采购方案；实际订单数量、舵机修订、调试板具体型号及随货配件待订单或到货核对。没有把此前商品截图的促销价作为本次成交价。
- 官方产品入口见 [按厂家采购清单](M1.52_按厂家采购清单_2026-10-06.md)；尚未提供的成交链接与金额保持空缺，不计入已知金额合计。
- 两类舵机调试板是外部台架工具，不增加整机内部板卡。此次下单确认不包含 ST-Link；用户随后确认可借用公司的 J-Link，见下方下载工具安排。
- 全部待收货，实物复核为 **NOT_TESTED**。到货后核对 SCS0009 舵盘／花键与附件、S288 输出连接附件，以及 WeAct 实发版本和排针方向；本次采购记录不改变现有模型、硬件合同及未完成的适配状态。

## 2026-10-07：WeAct 下载工具安排

用户提供 [WeAct 官方下载教程](https://www.weact-tc.cn/2019/11/30/STM32Download/)，并确认：“实在不行，我可以用公司里的 J-Link 烧录。”

- 优先通过 WeAct 板载 USB 的 DFU 模式烧录，使用数据线和 STM32CubeProgrammer；不是通过舵机调试板下载主控固件。
- USB 烧录遇到问题或需要 SWD 在线调试时，借用公司的 J-Link。具体型号、转接线与实机连接待使用时核对；不记为本项目已购买的设备。
- **暂不新增采购 ST-Link／SWD 调试器**，主控下载工具不再列为待购项。
- 本次仅确定工具来源和下载途径，尚未进行实物烧录或调试，状态为 **NOT_TESTED**。

## 2026-10-08：头部舵机完整型号确认

用户明确确认：“我买的是 SC-0090-C001”。已购头部舵机记录为 **飞特 SC-0090-C001／SCS0009 单轴版本**；不再将商品型号或用于识别型号的订单链接列为待用户提供的输入。该型号与此前用户商品截图中的单轴选项一致。

- [飞特官方产品页](https://www.feetechrc.com/6v-23kg-serial-bus-steering-gear_65522.html)同页列出商品编号 SC-0090-C001 与型号 SCS0009，下载项也标为 SC-0090-C001.pdf。2026-10-08 重新核对了网页；本地已保存的下载资料仍是 SCS0009 A/0、2020-11-23 规格书，不能把上传路径日期当作产品修订。
- 型号已确认；**实发修订、花键与配套舵盘／中心螺钉／分线板仍未确认**。官网介绍写 25T，参数表与本地 A/0 PDF 写 20T／Ø3.95 mm；PDF 第7页写无配件，第8页又有套装照片。完整商品编号本身不能消除这些资料冲突，也不能证明实际随货内容。
- 采购进度仍为已下单、待收货。项目配置仍为 2 个；实际订单数量、成交价和订单链接未提供，不补造数据或计入已知金额。机械模型与舵盘接口不因本次记录而改变，实物复核保持 **NOT_TESTED**。
- [型号确认与来源记录](evidence/2026-10-08_SC-0090-C001_confirmation.json)。本次确认仅记录采购型号，不改变机械接口。
- 已整理[到货前资料询问稿](SC-0090-C001_到货前资料确认.md)，用于匹配实发花键、舵盘、中心螺钉和尾线附件；尚未发送供应商。2026-10-08 用户明确改为到货后核对，不再等待发送授权。

## 2026-10-08：到货后核对的安排

用户确认“马上到货，这块先不管，到货再调整”。SC-0090-C001 实发舵盘／花键／配件，以及微雪 CAM／LCD 排线与插座尺寸暂不向供应商追问；两份询问稿保留且未发送。到货后记录实际修订、尺寸与附件，再据此调整。相关接口保持 **BLOCKED**，实物复核 **NOT_TESTED**，不视为模型验证通过。

## 2026-10-08：喇叭实物线长

用户查看实物后确认，喇叭从**外壳出线处到现有插头末端为 150 mm**，末端已有插头。见[实物报告记录](evidence/2026-10-08_SP3040_lead_measurement.json)。本条只确认这一段总长及插头存在；量具、误差、插头尺寸／型号、极性和线径尚未提供。

- 原规格书标注的 200 mm 保留为文档依据；此件实物的长度规划改用用户报告的 150 mm，不再把 200 mm 当作实发可用长度。
- **150 mm 含插头，不等于 150 mm 可弯曲导线**，也不是裁线尺寸。不能仅凭已有插头或“2p1.25”标签认定可直接接 CAM。
- 已知实物在用户手边；未据此推定其余采购件均已到货。喇叭成交链接、价格及实发完整标签仍未提供。
- 当前主模型未包含完整喇叭线束。本次记录不改变喇叭外形、安装孔和已批准结构；后续走线复核引用本记录。

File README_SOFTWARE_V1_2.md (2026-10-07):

# MORI V1.2 软件

本工程已按用户提供的 `MORI_SPEC_V1_2.md`、`software/inputs/v1_2/03_CODEX_SOFTWARE.md` 更新，保留已有软件与旧台架回归。**当前只开发网页，App 暂停**，这个用户要求优先于附件中的 App 条目。

网页、模拟设备、语音 mock/服务适配、SQLite 记忆、视觉像素输入及有界活动/跟随/巡游继续可运行。运动默认构建对齐已选 STM32F412RET6（512 KiB Flash / 256 KiB SRAM）；新增 S288、SCS0009、ICM42688 数据解析、安全核心与分段计时钩子。交互改为 16 MB Flash、360×360 目标，锁定并编译 ST77916 QSPI、ES7210/ES8311、CH32V003 与 OV3660 相关依赖。

**机器人是否已经能自平衡站立：尚未验证。** 新 STM32 镜像是禁驱启动镜像；编译和模拟不代表实机已接通、能旋转或能平衡。`reports/v1_2/acceptance.md` 区分实现、HOST_TEST/SIMULATION 与 BENCH/ROBOT。

## 启动网页

在 `/Users/dean/Documents/MORI` 的两个终端中运行：

```sh
.venv/bin/python -m backend.run
bash tools/node-env.sh dev
```

打开 http://127.0.0.1:5173 ，用 `.state/pairing.txt` 的一次性码绑定本地模拟设备。取得控制权 → 明确勾选模拟解锁 → 前进 100 mm → 停止移动。停止后健康模拟平衡继续；松手、失焦、隐藏、断线终止续租。刷新或重连不重放旧动作。

视觉页 TRACKING → 确认目标 → 头跟踪/模拟底盘跟随；多人/遮挡/陈旧帧/头角反馈失效撤销位移。仅限清场、看护、无台阶环境的未来实测；当前不宣称避障、防跌落或自由巡游。连续视觉不默认上传或留存。语音默认 mock 回复及测试音，不能当作真实中文 TTS/AEC/自定义唤醒成功。

## 构建与验证

```sh
# 全部主机、原回归、协议、Web 类型/构建和 360×360 双眼测试
.venv/bin/python tools/verify-v1_2.py
# 桌面与手机尺寸 Chromium；需先启动上面的 Vite
MORI_REPORT_ROOT=reports/v1_2 .venv/bin/python tools/record.py browser_local -- bash tools/node-env.sh exec playwright test --config apps/console/playwright.config.ts
# 两域固件，只构建
bash tools/build-firmware.sh motion
bash tools/build-firmware.sh interaction
# 保留原 ESP32 台架工程的显式入口，不适用 V1.2 接线
bash tools/build-firmware.sh legacy-motion
# 离线协议及命令回放，无串口连接
.venv/bin/python -m simulation.s288_replay simulation/fixtures/SIMULATED_s288.jsonl --output reports/v1_2/SIMULATED_s288.csv
.venv/bin/python -m simulation.replay simulation/fixtures/SIMULATED_session.jsonl --output reports/v1_2/SIMULATED_commands.jsonl
.venv/bin/python -m simulation.dynamics --output reports/v1_2/SIMULATED_dynamics_v1_2.json
```

新机器：Node 24.19.0/pnpm 11.19.0、Python 3.12，按 `pnpm-lock.yaml`、`backend/requirements.lock` 安装。STM32 使用 Arm GNU 14.2.Rel1、CMake/Ninja；运行 `python tools/fetch-v1_2-refs.py` 获取锁定源码，`python tools/bootstrap-arm.py` 下载并校验工具链，或设置 `MORI_ARM_BIN` 为已核验工具链的 bin 目录。ESP-IDF 固定 5.5.2，本机路径 `/Users/dean/esp/esp-idf`；可用 IDF_PATH 指定同版本。没有自动安装系统服务、打开端口、扫描串口、刷写或远程部署。

构建输出：`firmware/motion/build_stm32/mori_motion.elf/.bin`；`firmware/interaction/build_v1_2/mori_interaction.bin`。STM32 只启用内部 HSI 和 HAL 系统 tick，没有假造板 GPIO、PLL、收发器使能或驱动功率链；纯算法/协议模块已编译并在主机测试。电机 DMA/SPI 端口接线、实时调度、物理命令桥、ICM 初始化/滤波配置仍待板契约接入，不能把这个镜像当作可直接驱动整机的成品。

## 版本与兼容

| 项目 | 当前软件 | 物理边界 |
|---|---|---|
| 控制台/后端 | 1.2.0-dev.1，MORI/2 向后兼容字段扩展 | 仅模拟连接，实机解锁 BLOCKED |
| STM32 | F412Rx CMSIS v2.6.10 + HAL v1.8.3；Arm GCC 14.2.1 | 板型/时钟/管脚/安全链未释放 |
| S288 | 显式 20/26 字节、独立 CRC、齿比一次转换、TC 方向释放状态、限时双轮轮询 | 停止语义、电平、6 Mbps 波形、实际带载扭矩未测 |
| SCS0009 | 大端位置/速度/负载反馈；需标定的 joint 映射；联合可达域回调 | 零点/带载限位/联合区域/重力保持未测 |
| ICM42688 | WHO_AM_I 与 14 字节 SI 解码、正交旋转矩阵校验 | 模块、SPI/DRDY、量程/滤波/零点及实时驱动接入待核 |
| 交互域 | IDF 5.5.2、LVGL 9.2.2、ESP-SR 2.2.0、camera 2.1.4、codec 1.5.4、ST77916 1.0.1、CH32 1.0.1 | FPC、电源、音频槽、AEC、相机/显示/音频/Wi-Fi 同时运行未测 |
| 电源/控制 | 3S 候选；保护阈值 null，实机增益与出力上限 0 | 不继承旧 2S 阈值或 PWM 增益 |

MORI/2 保留相同 33 命令。新增软件/参数版本与 `sensors.*.valid`；没测量的数值和采集时间均 null，已有模拟关节估计单独保留。默认软件 profile 在 `contracts/software_profile.json`，只记录软件目标与门控；机械/电气真源仍由硬件任务维护。

并行任务已更新 `V1.2-H0.1` 电气与 `V1.2-M1` 机械契约，本轮读取合并，未编辑它们。新电气契约已采用 MORI/2 128 字节载荷/158 字节帧；板间波特率仍 null。几何轮径 95 mm 等属于结构 ASSUMED，不自动升级为控制标定。文档提及但未提供的 AGENTS_MORI_TEMPLATE.md、04_HANDOFF_AND_ACCEPTANCE.md、REFERENCES.md 未冒称已读。

台架步骤/记录：`docs/debug_manual_v1_2.md`；分段时序：`docs/realtime_v1_2.md`；变更：`software/interface_change_requests.md` / `reports/decisions/ADR-SW12-001.md`；依赖与许可：`software/THIRD_PARTY_V1_2.md`。

离线动力学补充了供电能力下降、头部质量/惯量与pitch反作用，保留延迟、饱和、死区、噪声和轮滑。它仍是 **ASSUMED 加速度输入模型**，不等同 S288 扭矩对象；说明及未建模项见 `docs/dynamics_v1_2.md`。实机增益保持0。

2026-10-07 复核：编译目标改用锁定 CMSIS 的 startup_stm32f412rx.s、STM32F412Rx 宏和专用 STM32F412RE.ld。保留旧 F413 链接脚本供历史复现；它不再是默认目标。容量依据 [ST 官方 F412RE](https://www.st.com/en/microcontrollers-microprocessors/stm32f412re.html)。这只修正目标和内存边界，现有禁驱门保持；不是 GPIO/时钟/实时端口已接通。

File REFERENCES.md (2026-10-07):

# V1.2 source index recovery

The original user-supplied `REFERENCES.md` and its S01–S08 mapping were **not supplied**. This file was added during archive review on 2026-10-07. The table is a contextual cross-reference to the recorded HW12 source catalogue, not a claim that the original mapping was recovered or that any hardware was measured.

| Spec marker | Context in the specification | Recorded reference |
|---|---|---|
| S01 | S288 nominal specifications | [Unitree S288 current Chinese specifications](https://www.unitree.com/cn/DigitalServo/); [Unitree J288/S288 manual](https://www.unitree.com/images/无刷数字舵机J288S288使用手册.pdf) |
| S02 | S288 protocol example | [Unitree digital_servo v1.0.1](https://github.com/unitreerobotics/digital_servo/archive/refs/tags/v1.0.1.zip) |
| S03 | SCS0009 interfaces | [FEETECH SCS0009 A/0 2020-11-23](https://www.feetech.cn/Data/feetechrc/upload/file/20220915/6379883463905538176347522.pdf) |
| S04 | CAM33700 | [Waveshare CAM SKU33700](https://docs.waveshare.com/ESP32-S3-CAM-OVxxxx); [Waveshare CAM schematic](https://files.waveshare.com/wiki/ESP32-S3-CAM-OVxxxx/ESP32-S3-CAM-XXXX-schematic.pdf) |
| S05 | LCD35079 | [Waveshare LCD SKU35079](https://docs.waveshare.com/1.85inch_Touch_LCD_Module) |
| S07 | ICM-42688-P | [TDK DS000347 ICM42688P](https://www.lcsc.com/datasheet/C1850418.pdf) |
| S06 | Not cited in the supplied V1.2 specification | Original meaning unknown; no replacement invented. |
| S08 | Charging architecture / rejection of old 2S design | Original reference unknown; no final 3S charger qualification is implied. See the current electrical contract and procurement blockers. |

[Full source catalogue](hardware/v1_2/sources/index.json) contains access dates, source IDs and original limitations. [Software source lock](software/references_v1_2.lock.json) pins protocol/example code. Manufacturer nominal values and archived reviews do not establish availability, current pricing, physical fit or electrical qualification.

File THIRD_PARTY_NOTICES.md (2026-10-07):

# MORI V1 第三方通知

> V1.2新增STM32、Unitree/FTServo协议参考与微雪组件见 [THIRD_PARTY_V1_2.md](software/THIRD_PARTY_V1_2.md)。下文保留原V1依赖版本；不是当前camera组件版本。

这些说明记录本次软件参考、复制与链接来源，未替用户授予模型、声音、形象或商标权利。
所有参考 commit / 每个归档文件 SHA256 在 `refs/sources.lock.json`；所有归档标为参考资料，不参与编译。

| 本工程文件 | 来源文件 | 使用方式 / 许可 |
|---|---|---|
| apps/console/src/eyes/reference-face.ts | jeremy-prt/bloub src/bot/face.ts | 未修改副本 / MIT, ©2026 Jérémy Perret |
| apps/console/src/eyes/math.ts | jeremy-prt/bloub src/bot/math.ts | 未修改副本 / 同上 |
| apps/console/src/eyes/engine.ts | 上述投影与liveliness函数；MORI状态/裁切/切换新增 | 适配 / 同上，保留完整 LICENSE.bloub |
| firmware/interaction/core/eyes.c | bloub face.ts/math.ts 的投影、noise、RNG与blink | C移植 / 同上，文件头及 docs/licenses/bloub-MIT.txt |
| backend/mori/xiaozhi.py | 78/xiaozhi-esp32 docs/websocket.md | 按协议独立适配，未复制Application；源仓库MIT |
| firmware/motion/components/mori_v1/* | MORI新增；参考StackChan限位与生命周期概念 | 不含StackChan/hover源代码；不继承其整套控制参数 |
| apps/mobile/ios/*、android/* 原生模板 | @capacitor/cli7.2.0 | 生成模板，MIT；MORI另加UIScene/权限配置 |

运行依赖：Vue/Vite/TypeScript/Capacitor/Vitest/Playwright及传递依赖许可由包本身保存，版本和完整性由
pnpm-lock.yaml锁定。后端 FastAPI/Starlette/Uvicorn/httpx/PyAV/numpy/OpenCV/TencentSDK及其传递依赖
记录在 reports/v1/python_dependency_licenses.json 与 requirements.lock。PyAV源码为BSD，轮子内FFmpeg
及各编解码依赖须按随包LICENSE核验再分发；后端开发可使用，商业打包状态未声称已审完。
OpenCV内Haar模型为检测候选，不存储身份模板，也不宣称人脸身份识别已授权或实现。

固件链接 LVGL9.2.2(MIT)、esp32-camera2.0.16(Apache-2.0)、ESP-SR2.2.0(Espressif MIT，限Espressif产品)
及锁文件中的组件。完整声明留在managed_components，额外快照在docs/licenses。
原 motion 驱动继续沿用既有HW交接源与原通知；硬件快照本身未改。

rig_omni 缺少顶层明确许可，因此只阅读/分析控制路径，**没有复制**其中Hover控制代码到运行工程。
StackChan-BSP(MIT)、stack-chan(Apache-2.0)、xiaozhi-server(MIT)、ESP-WHO(Espressif MIT)是锁定参考，
未把它们的主循环混合到本工程。各参考目录的不同子模块可能有独立许可，不把仓库许可一概套给每个第三方文件。

bloub代码MIT不代表Grok/xAI角色商业形象许可。当前皮肤用于开发对照，MORI提供可替换皮肤接口；
对外商业版本应切换为有权使用的MORI原创设计。离线“你好，莫里”训练模型、声音API、腾讯云服务费用/权利
尚需单独确认；不模仿指定真人，不把网页订阅当API授权。

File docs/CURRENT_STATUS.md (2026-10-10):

# 当前状态与验证边界

2026-10-10：当前主模型 **V1.2-M1.55**，装配动画 **M1.55-A1**，硬件合同 **V1.2-H0.5-P5R7**。工程保持 **PROTOTYPE / UNVALIDATED**，manufacturing_release=false。

## 当前主模型已采用

| 改动 | 实际范围 |
|---|---|
| M1.53 C6 通道 | 固定偏航桥左侧现有槽口外缘加宽 0.8 mm；轴承座、孔位和五金保持 |
| M1.54 CAM 方向 | CAM 整板及板载双麦绕不变板中心转动 −90°，USB 朝机器人 +X／右侧；相机及 LCD 不动 |
| M1.55 R2 颈部装入 | 仅 Pitch_Yoke 内部孔道和后侧颈壁改变；与批准网格差 0 mm³，其余 200 件原生零件和全部硬件位姿保持，轴承配合外圆保持 |
| 模型与动画 | 主模型、电子细模、21 个 STL、62 个视图和动画同步；机器人本体打印件仍为 16 件，不增零件或螺钉 |

当前几何报告为 **27 PASS、0 FAIL、10 NOT_TESTED、12 BLOCKED**，仅针对记录的检查范围。裸反力夹连续装入、壳体俯仰、130 个组合姿态及压板／身体装入检查通过；实际 SC-0090-C001 舵盘、花键、锁紧和完整带线初装仍 BLOCKED，PA12 强度 NOT_TESTED。

视频为 22 步、2,100 帧、24 fps、1280×720、87.5 秒。动画已做刚体回读，完整研究线束未采用。

[最新模型入口](../mechanical/LATEST_MODEL.md) · [M1.55 更新与证据](M1_55_MODEL_UPDATE.md) · [图册](../mechanical/index.html) · [视频](../mechanical/animation/index.html) · [检查报告](../mechanical/current_report.html)

## 仍未完成

| 工作 | 当前状态与实际限制 |
|---|---|
| 完整线束路线 | 12 条参考前段和 7 条已知上段的名义连续检查、互线、自身和接续通过；三条舵机与两条喇叭上段仍缺真实接口，不是完整成品线束资格 |
| 实际材料和裁线 | 最终材料、公差、粗细线接续、端子第一可弯点及供应商裁线尚未冻结；所有参考长度不是裁线尺寸 |
| 端接与应力释放 | H06 身体端厂家压接、四端子装机后入壳已由用户接受；真实压接、保护、入壳、插合、夹持和止拉仍未完成 |
| 带线装配和闭壳 | 裸端子容量路径通过；已检的预铺／搬入参考方式有相交。实际带线穿入、临时整理、完整插合、拆壳和闭壳仍 BLOCKED，候选未进入主模型或视频 |
| 头部传动配件及排线 | SC-0090-C001 舵盘／花键／锁紧和微雪 FPC／FFC 按用户决定到货后核对 |
| CAM 供电 | USB 朝右已采用；R2／R3 电源与插口研究未替换原生 PCB 或正式接口，等待硬件正式交接 |
| 喇叭 | 用户报告壳体出口至现有插头末端 150 mm，含插头；完整插头型号、外形、配对及路线待补充 |
| WeAct E 插合 | 原厂 STEP 自身存在针孔相交；不据此判断实物兼容或不兼容 |
| 供电与安全 | 电池候选、充电外部件、物理断电／急停和维护互锁未完成实际验证；取消外露开关不等于取消安全要求 |
| 实物验证 | PA12 配合、嵌件、轴承、强度／疲劳、线束寿命、上电、热、EMC、电池安全、实机平衡和续航尚未验证 |

当前等待实际接口资料。完整线束还有路线、材料／裁线、端接固定、带线装配／闭壳四组工作；没有把目标标记完成。

[到货前依赖清单](PREARRIVAL_BLOCKERS.md) · [未采用研究摘要](../mechanical/studies/harness_M1_55_summary/index.html) · [厂家资料获取状态](../mechanical/procurement/JST_PH_资料获取状态.md)

## 采购与发布

微雪 LCD35079、CAM33700、头部／轮驱舵机及调试板、WeAct F412 已由用户确认购入。头部商品编号 SC-0090-C001。喇叭 150 mm 线长来自用户实物报告，其余字段不自动成为 MEASURED。

本次资料 PR 更新已采用 M1.55 几何、动画、采购记录、状态导航和可恢复证据包。未采用线束、电源方案及受限厂家资料未成为正式模型；本地大型研究资产保留。询问稿未发送，没有采购、制造或上电。

硬件工程和 contracts/components.json 保持原字节，机械仅接收交接。硬件候选快照的公开范围及重放限制见 [M1.55 更新](M1_55_MODEL_UPDATE.md)。

[采购记录](../mechanical/procurement/采购记录.md) · [历史 M1.54 更新](M1_54_MODEL_UPDATE.md) · [归档与恢复](GITHUB_ARCHIVE.md)

## 软件与证据词汇

F412RE 的 2026-10-07 交叉编译和主机测试见 [审查修复](REVIEW_CLOSURE.md)，本次机械整理未重跑软件验收。旧 F413 证据不代表当前 F412／P5R7 的实机验证。

PASS／FAIL 仅针对该项记录；NOT_TESTED 为未执行，BLOCKED 为缺输入或未解决，NOT_APPLICABLE 为不适用。几何检查、ERC／DRC 和仿真均不等于物理或制造资格。

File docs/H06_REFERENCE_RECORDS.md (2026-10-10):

# H06 引用资料与状态边界

本页对应采购交接中引用的 **M1.54 历史容量研究**。它们没有进入主模型，不能作为 M1.55 完整线束、真实端接或带线闭壳的通过证明；正式 AWG28／PH002 与厂家 SH 尾线保持。

公开的[字段摘录](review_evidence/H06_reference_summary.json)由原报告提取，逐份记录来源路径与 SHA-256。[原始数值报告包](evidence/M1_54_H06_referenced_evidence.zip)包含 34 份未修改的报告、命令记录及入壳要求；[包清单](review_evidence/M1_55_archives.json)的 `h06-reference` 组列出每个成员与哈希。未包含完整研究脚本、二进制几何缓存或第三方原件，因此不宣称可重跑全部研究。

## 穿线容量研究

端子保护容量盒为 2.28 × 1.7 × 6.7 mm，属于未选定的几何探针。原报告在 `cam_terminal_feed/optimized_path_verify/review.json`。

四根参考线按 CAM_4 → CAM_3 → CAM_2 → CAM_1 逐根送入；检查使用机械零位及未采用的研究线径。`joined_independent_verification.json` 记录首根下段 4,168 个区间；前三根让位的独立报告分别记录 258、130、128 个区间，第三根另有 4 个 S 段抬升区间。

第四根端子路径由 `fourth_slack_enclosure/terminal_upper/review.json` 的 2,310 个上段区间和沿用的 `connected_neck_joined/rigid/review.json` 的 735 个下段区间组成，共 3,045 个。`fourth_slack_enclosure/review.json` 记录 440 个松线弯扫掠单元，`fourth_attached_continuous/review.json` 及 `fourth_independent_verification.json` 记录 4,168 个下段活动线区间。第三根暂放段的独立数值最小半径约 1.466 mm。这些几何检查没有批准具体线材，材料限制见下一节。

## 材料对照

`cam_terminal_feed/material_boundary/review.json` 保留了来源字段、每阶段半径及明确的 FAIL：Alpha 2841/7 的外径为 0.6096±0.0508 mm，记录的厂家弯曲要求为 10 倍外径，按最大外径需 R6.604 mm。研究路线约 R2.990／R1.466 mm，不能据此采用该材料。它是 AWG30，外径也低于现行 PH002 绝缘夹持范围；未替换正式 H06。

## 入壳要求

包内 `cam_terminal_feed/housing_requirements.md` 保存完整交接，`material_boundary/receipt.json` 保存原始来源回执。用户已接受厂家压接、身体端暂不装 PHR-4 塑壳，装机后按原孔号入壳。

孔号和信号以[现行逐针接线表](../hardware/v1_2/wiring_P5R7/03_逐针接线表.csv)为准。压接后最大外形、保护方式、锁舌朝向、入壳运动、对插和完整带线闭壳仍未完成，不可下发裁线长度。

## 未采用的 AWG28 参考

`cam_AWG28_reference/independent_verification.json` 记录 Alpha ThermoThin 2628 的首根下段 1,314 个连续曲率区间和保守中心线 R4.0513 mm；没有覆盖其余三根全流程。最大外径 0.7366 mm 在 1 mm 出口中心距下仅留 0.2634 mm 表面间隙，低于 0.3 mm 目标，是余量不足，不能说实物已经相撞。

该参考需要 PH004；正式 PH002 与厂配 SH 尾线未变。整体仍为 **BLOCKED**。材料版本、厂配尾线、压接及物理装配待确认。

## 查看完整记录

从仓库根目录执行：

```sh
python tools/restore_m1_55_evidence.py --group h06-reference
```

恢复位置为 `mechanical/studies/harness_current_M1_54/` 下的两个研究目录。恢复器先检查全部目标；不同内容的现有文件不会被覆盖。无需依赖旧预览服务器或未发布的本地路径。

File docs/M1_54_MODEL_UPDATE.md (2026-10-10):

# M1.54 模型同步

把用户已确认的两项改动同步到 Blender 主模型、电子细模、STL、图册和装配动画。相对 GitHub 原 M1.52 基线，固定偏航桥现有左侧槽口外缘加宽 0.8 mm；CAM 整板和板载双麦转动 −90°，USB 朝机器人右侧 +X。没有新增打印件、螺钉或线束。

- [C6 实际剖面对比](../mechanical/studies/c6_adoption/index.html)
- [CAM 转向前后对比及安装路径](../mechanical/studies/cam_right_adoption/index.html)
- [当前模型图册](../mechanical/index.html) · [主模型](../mechanical/mori_v1_2.blend) · [装配视频](../mechanical/animation/index.html)
- [当前检查报告](../mechanical/current_report.html) · [未完成事项](CURRENT_STATUS.md)

## 重建与证据

主流程使用实际 Blender 命令完成构建、结构元数据、几何检查、62 视图渲染、21 个 STL 导出、金属件设计参考导出、交付一致性及报告生成。具体命令、时间、输入／输出哈希和日志位于 [流水线执行包](../mechanical/reports/pipeline_execution.zip)。衍生模型和动画独立回读，当前发布结果另记于 [交付复核](review_evidence/M1_54_publication.json)。

新增的批准前基线、精确网格和原工具扫掠共 26 个文件，按原字节压缩到普通 Git 文件 `mechanical/input_assets/m1_54_approval_inputs.zip`（约 0.65 MiB）。[恢复清单](archive_assets.json)记录每个成员的大小、SHA256 和包哈希。先按[归档说明](GITHUB_ARCHIVE.md)恢复源模型，再运行：

```sh
python3 tools/restore_archive_assets.py --group mechanical-build-inputs --group native-pcbs
MORI_CAD_PYTHON=/path/to/cad-python python3 mechanical/scripts/run_all.py --core
```

完整当前流程还依赖归档说明中的厂家数据及 legacy helpers。解包会拒绝覆盖已有的不同文件。三份 Blender 工程继续使用 Git LFS，视频、STL 和本次小型基线包使用普通 Git。

历史保护清单曾误收录一个 `__pycache__/*.pyc` 文件。本次保留原清单，只在源文件保护检查中明确排除该机器生成缓存；302 个实际硬件源文件仍逐个校验，任何源文件不匹配均失败。两份批准前配置现在也验证记录中的原始 SHA256。

另修正动画回读：读取原生碰撞体前先恢复验证集合并刷新装配变换。独立诊断确认原流程会留下 4 个屏幕／螺钉碰撞体的旧矩阵；修正只影响检查流程，不改变模型、动画轨迹或打印件。

## 范围与限制

现有 201 个原生零件、130 个组合头部姿态、拓扑、光学及核心路径按当前输入复核。CAM 的原四孔轴集合和固定件保持；三种 USB 本体只是有尺寸边界的空间预留，不是完整采购件或插合实测。C6 改动以独立批准网格复核，原始比较记录仍注明 M1.53 日期。

装配动画仍为 22 步、85.75 秒、1280×720、24 fps；CAM 阶段沿已检查的折线路径运动。视频用于装配说明，不证明连续扫掠、人手操作、完整线束或制造可行性。

用户已决定 SC-0090-C001 配件及微雪排线资料待到货后核对；两份询问稿保留且未发送。完整线束、上部反力夹初装、正式 USB 源端、电源替代候选及实物验证均未由本次局部改动放行。硬件源和 `contracts/components.json` 保持不变。

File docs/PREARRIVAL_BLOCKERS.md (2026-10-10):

# 到货前剩余工作与资料依赖

2026-10-10。用户决定先等待实物与接口资料。本页保留完整待办，不能解释为所有到货前工作已经完成。当前主模型 M1.55、视频 M1.55-A1、硬件合同 P5R7。

| 工作 | 已完成的具体范围 | 仍缺的输入或工作 |
|---|---|---|
| 完整路线与运动 | 12 条身体／颈部参考前段、7 条已知上段及其名义运动、互线、自身和接续检查 | 三条头舵机和两条喇叭参考的真实端点、尾线及配对附件 |
| 实际材料、接续与裁线 | 厂商字段对照及数值参考长度 | 最终线材外径公差、弯折资料、原配尾线、接续和端子基准；参考长度不能下发裁线 |
| 端接、夹持与应力释放 | 正式 H06 针表；厂家压接、身体端四端子暂不入壳的交付选择 | 实际 CAM 配对、PH 内腔／压接／装配资料、供电接口、第一可弯点和操作空间 |
| 带线装配、闭壳和同步 | 当前裸件装配、部分未采用容量研究 | 实际带线逐根穿入、临时整理、插合、应力释放、拆壳／闭壳及全套验证后再同步模型和视频 |

目前等待：

- 用户到公司后补充 SP3040 插头针数、针距、外形或完整型号。已确认壳体出线处至现有插头末端 150 mm，含插头，不再重问线长。
- SC-0090-C001 实发尾线、配件、舵盘和锁紧叠层；微雪 FPC／FFC 按用户决定到货后调整。
- 硬件任务正式交接 CAM 供电源端及完整安装接口。R2／R3 候选不等于原生 PCB 已更新。
- 线材与实际压接资料。Daburn 询问稿为 DRAFT / NOT_SENT，既有发送授权问题尚未答复；本次 PR 不发送消息或选定线材。
- PH 专用手册和详细几何。已定位的官方入口需要登记、接受条款并由邮件领取；没有提交登记或取得受限资料。[获取记录](../mechanical/procurement/JST_PH_资料获取状态.md)

目前没有足够输入完成这些实际接口，完整线束保持 BLOCKED。候选几何通过只覆盖注明的参考；此前预铺和整体搬入方式已有相交记录，不能直接作为安装顺序。

到货后按接口逐项接收证据，再确定路线、实际材料长度、端接与固定，完成带线装配后同步正式模型和视频。结构、孔位或选型有不确定变化时，按用户要求先提供可审阅方案确认。

[当前状态](CURRENT_STATUS.md) · [研究摘要与记录包](../mechanical/studies/harness_M1_55_summary/index.html)

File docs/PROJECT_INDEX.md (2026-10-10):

# 当前项目资料索引

资料基线为 M1.55／P5R7，整理日期 2026-10-10；工程仍为 PROTOTYPE / UNVALIDATED。

| 内容 | 当前入口 |
|---|---|
| PR 顺序与依赖 | [REVIEW_STACK](REVIEW_STACK.md) |
| 当前状态与未完成项 | [CURRENT_STATUS](CURRENT_STATUS.md) · [M1.55 更新](M1_55_MODEL_UPDATE.md) |
| 到货前工作与研究证据 | [待补资料](PREARRIVAL_BLOCKERS.md) · [研究摘要](../mechanical/studies/harness_M1_55_summary/index.html) · [证据包清单](review_evidence/M1_55_archives.json) |
| 规格与规则 | [V1.2](../MORI_SPEC_V1_2.md) · [AGENTS](../AGENTS.md) |
| 机械唯一尺寸源 | [geometry.json](../config/geometry.json) · [机械接口](../contracts/mechanical_interfaces.json) |
| 硬件选型与电气契约 | [components](../contracts/components.json) · [electrical_interfaces](../contracts/electrical_interfaces.json) |
| 原生运动载板 | [MORI_motion_P5R7.zip](../hardware/v1_2/native_projects/MORI_motion_P5R7.zip) |
| 原生电源板 | [MORI_power_P5R6.zip](../hardware/v1_2/native_projects/MORI_power_P5R6.zip) |
| 原生 IMU 板 | [MORI_imu_P5R4.zip](../hardware/v1_2/native_projects/MORI_imu_P5R4.zip) |
| 原生后接口板 | [MORI_rear_P5R7.zip](../hardware/v1_2/native_projects/MORI_rear_P5R7.zip) |
| 正式机械交接 | [mechanical_P5R7](../hardware/v1_2/handoff/mechanical_P5R7.json) |
| 接线与 BOM | [wiring_P5R7](../hardware/v1_2/wiring_P5R7/README.md) · [bom.csv](../hardware/v1_2/bom.csv) |
| 模型、STL 与动画 | [机械说明](../mechanical/README.md) · [图册](../mechanical/index.html) · [STL](../mechanical/exports/) |
| 网页、后端与仿真 | [apps/console](../apps/console/) · [backend](../backend/) · [simulation](../simulation/) |
| 固件与验证工具 | [firmware](../firmware/) · [软件说明](../README_SOFTWARE_V1_2.md) · [tools](../tools/) |
| 历史与完整证据 | [历史索引](HISTORY.md) · [归档与恢复](GITHUB_ARCHIVE.md) |

原生 PCB 需先按 [解压说明](../hardware/v1_2/native_projects/README.md)恢复完整工程，原理图和设计规则仍可直接查看。

`config/project_baseline.json` 已按当前 P5R7 接收集校正；原生 PCB 字节未变。默认运动固件改为 F412RE 并已交叉编译，板级接通与实机测试仍未完成。代码审查修复及实际验证见 [复核记录](REVIEW_CLOSURE.md)。

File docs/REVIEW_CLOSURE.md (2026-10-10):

# 2026-10-07 代码审查修复记录

复核范围为拆分 PR #2–#11 的 52 条意见及最终组合树。原始资料快照保留；本轮修复源码、资料可复现性和已确认的网格碎片。**这是原型资料归档的代码审查，整机仍未制造放行。**

## 实际验证

- 网页 13 项测试、Vue 类型检查和生产构建通过。真实 Chromium 验证凭据刷新、序号恢复、同模式授权切换、describe POST、撤销后重新配对；无浏览器错误。
- 后端/仿真 57 项、旧软件 24 项、证据与恢复工具 15 项测试通过；V1/V1.2 C 核心通过 ASan/UBSan。
- F412RE 使用 Arm GNU 14.2.Rel1 实际交叉编译。开启物理平衡门的负向构建被拒绝；没有烧录或上电。
- 最新 R5 机械交付包包含 853 个文件，独立解压后逐文件哈希、完整执行证据及篡改生成脚本的拒绝检查通过。当前主模型八阶段 core 重建通过，62 个渲染视图均为 1200 px / 32 samples；此前 R4 包的独立完整重建及再次打包亦已通过，详见下方带日期的记录。
- 四个工程包只更新 JSON 元数据；所有 PCB、原理图、封装库及其余成员字节保持。
- Blender 5.2.2 LTS / manifold3d 3.5.3 重建完成；当前 130 个联合姿态等核心检查：25 PASS、0 FAIL、9 NOT_TESTED、10 BLOCKED。21 个 STL 均为单一连通实体。历史扩展检查未冒充本轮重跑。
- 局部修复范围按 201 个零件的世界坐标面片核对。头前壳只移除四个 <0.001 mm³ 游离碎片；Display_Frame 仅约 0.000002 mm 浮点变化，Display_PCB 对称差体积约 0.00000469 mm³。未改尺寸或硬件位置。

命令、版本、输出摘要和证据哈希见 [review_evidence](review_evidence/manifest.json)；原始源与复核关系见 [模型基线](../mechanical/input_assets/M1_52_review_baseline.json)。本轮视频未重渲染，保留的 M1.52-A1 是有日期的原始演示。

## 逐项处理

| 序号 | PR | 处理 |
|---|---|---|
| 1 | [#2](https://github.com/deanxizian/MORI/pull/2) | 补 REFERENCES.md；原 S01–S08 的对应关系明确标为 NOT_SUPPLIED，不猜造原作者来源。 |
| 2 | [#2](https://github.com/deanxizian/MORI/pull/2) | 后续固件层已有 THIRD_PARTY_V1_2.md；合并完整依赖树后链接可解析。 |
| 3 | [#2](https://github.com/deanxizian/MORI/pull/2) | 只忽略根目录 reports/v1、reports/v1_2，不再屏蔽 hardware 内的必要报告。 |
| 4 | [#3](https://github.com/deanxizian/MORI/pull/3) | 两个无载荷动作显式 POST {}；浏览器确认 describe 与 revoke 返回 200。 |
| 5 | [#3](https://github.com/deanxizian/MORI/pull/3) | 上传授权变化立即提交 CAMERA_MODE；以命令确认及服务端状态更新界面。 |
| 6 | [#3](https://github.com/deanxizian/MORI/pull/3) | 退出跟随同时清除头部目标和速度。 |
| 7 | [#3](https://github.com/deanxizian/MORI/pull/3) | C 测试夹具由紧随的固件层提供；完整树测试通过，不把中间层当独立产品。 |
| 8 | [#3](https://github.com/deanxizian/MORI/pull/3) | 按含路径的规范化完整网关地址保存凭据；刷新仅恢复认证，不自动占用控制权或 ARM。另修复重连序号回退。 |
| 9 | [#3](https://github.com/deanxizian/MORI/pull/3) | 会话变化、断线、重连立即拒绝并清除 pending commands。 |
| 10 | [#3](https://github.com/deanxizian/MORI/pull/3) | WAV 校验、预算拒绝与服务商错误分别处理；服务商异常不伪装为输入格式错误。 |
| 11 | [#3](https://github.com/deanxizian/MORI/pull/3) | 生成 JSON Schema 为各命令声明所需权限；99 个组合与运行时校验一致。 |
| 12 | [#3](https://github.com/deanxizian/MORI/pull/3) | 先 fsync 删除日志，再提交 SQLite；启动重放日志，崩溃后删除不丢失。 |
| 13 | [#3](https://github.com/deanxizian/MORI/pull/3) | 配对限速改成有界的每来源固定时间窗；错误尝试不能永久封死所有客户端。 |
| 14 | [#3](https://github.com/deanxizian/MORI/pull/3) | 零延迟立即生效；其他延迟按采样时刻插值。 |
| 15 | [#3](https://github.com/deanxizian/MORI/pull/3) | 未知回放场景直接报错。 |
| 16 | [#3](https://github.com/deanxizian/MORI/pull/3) | 心跳被拒绝或过期立即撤销本地租约并停止发送运动目标。 |
| 17 | [#4](https://github.com/deanxizian/MORI/pull/4) | DISARM、故障和释放冻结头部；HEAD_TARGET 及执行循环都要求已使能且通过相应门。 |
| 18 | [#4](https://github.com/deanxizian/MORI/pull/4) | 缓存全部保留的命令 ID 和结果，A/B/A 重试不再次执行或续租。 |
| 19 | [#4](https://github.com/deanxizian/MORI/pull/4) | 补两个小型基线 ZIP；新增只针对不可变快照的验证入口，44 个归档成员通过。历史完整审计缺资料时明确 BLOCKED。 |
| 20 | [#4](https://github.com/deanxizian/MORI/pull/4) | ARM 重置持续饱和计时与状态。 |
| 21 | [#4](https://github.com/deanxizian/MORI/pull/4) | 记录实际 Git HEAD、dirty 状态；去掉“没有 Git 仓库”的旧结论。 |
| 22 | [#4](https://github.com/deanxizian/MORI/pull/4) | 远端 CI 没有执行证据时标为 NOT_TESTED，不能由本地测试代替。 |
| 23 | [#5](https://github.com/deanxizian/MORI/pull/5) | BOM 对齐 motion/rear P5R7、power P5R6、IMU P5R4 的当前集合。 |
| 24 | [#5](https://github.com/deanxizian/MORI/pull/5) | 测试计划新增当前 P5R7 基线与前置条件；历史步骤保留明确边界。 |
| 25 | [#5](https://github.com/deanxizian/MORI/pull/5) | 合同改为已采用的 6806ZZ，30×42×7 mm。 |
| 26 | [#5](https://github.com/deanxizian/MORI/pull/5) | 合同按用户 SP3040 图纸记载；未标尺寸仍是估算。 |
| 27 | [#5](https://github.com/deanxizian/MORI/pull/5) | FFC 16–18 脚同步已收到 A2 的 NC 定义，实物方向复核仍待完成。 |
| 28 | [#5](https://github.com/deanxizian/MORI/pull/5) | 默认目标改为 STM32F412RE：正确启动文件、宏及 512 KB Flash / 256 KB RAM 链接边界；交叉编译通过，物理使能门保持关闭。 |
| 29 | [#5](https://github.com/deanxizian/MORI/pull/5) | 取消“可按表制作”的含义；每行长度与制造状态明确 NOT_TESTED/BLOCKED。这张表仅是端点定义，供应商裁线图仍未完成。 |
| 30 | [#5](https://github.com/deanxizian/MORI/pull/5) | PH 线壳的错误电容封装字段置空，明确其不是 PCB 焊接封装。 |
| 31 | [#6](https://github.com/deanxizian/MORI/pull/6) | 从四块实际 PCB 重新解析位置、转角、面及封装；重复运行不产生变化。 |
| 32 | [#6](https://github.com/deanxizian/MORI/pull/6) | 元数据中的交接/审阅链接指向固定归档提交，恢复工具也包含所需输入。 |
| 33 | [#6](https://github.com/deanxizian/MORI/pull/6) | 移除 rear 中误复制的 IMU 钢网通过结论；该项标为 NOT_TESTED。 |
| 34 | [#7](https://github.com/deanxizian/MORI/pull/7) | project_baseline 对齐当前 P5R7 接收集和工程包。 |
| 35 | [#7](https://github.com/deanxizian/MORI/pull/7) | 机械接口 MCU 记录对齐 WeAct F412RET6。 |
| 36 | [#7](https://github.com/deanxizian/MORI/pull/7) | 恢复清单包含 E-pin fit A1 交接，哈希对照原始提交。 |
| 37 | [#7](https://github.com/deanxizian/MORI/pull/7) | 扬声器待测项改为用户选择的 SP3040，保留耳厚/孔径等未测尺寸。 |
| 38 | [#7](https://github.com/deanxizian/MORI/pull/7) | 由 TDK 轴向图、原生 U1 转角及 PCB 变换导出名义 sensor→body = diag(1,-1,-1)；实物方向、标定与驱动配置仍未放行。 |
| 39 | [#7](https://github.com/deanxizian/MORI/pull/7) | 机械接口同样对齐 6806ZZ 及既定轴承座方案。 |
| 40 | [#7](https://github.com/deanxizian/MORI/pull/7) | 当前外壳接口删除已取消的电源开关出口；硬件断电/急停实施仍列为 BLOCKED。 |
| 41 | [#7](https://github.com/deanxizian/MORI/pull/7) | 检查结果遵守 PASS/FAIL/NOT_TESTED/BLOCKED/NOT_APPLICABLE；资料来源类别独立记载。 |
| 42 | [#8](https://github.com/deanxizian/MORI/pull/8) | 补固定哈希的公开 CAD/PDF/网格恢复清单和本地网格 ZIP；实际从恢复资料重建主模型成功。 |
| 43 | [#8](https://github.com/deanxizian/MORI/pull/8) | 视频先写唯一临时文件；成功后原子替换，并写 rendered_video、文件大小及 SHA256；失败不会拿旧 MP4 冒充本次输出。 |
| 44 | [#8](https://github.com/deanxizian/MORI/pull/8) | 构建清单读取实际 manifold3d 安装版本，本次为 3.5.3。 |
| 45 | [#9](https://github.com/deanxizian/MORI/pull/9) | M1.44 以后路由到当前报告生成器；缺失、过期或不匹配模型的证据会失败，不覆盖历史图册。 |
| 46 | [#9](https://github.com/deanxizian/MORI/pull/9) | 打包输入从构建清单与恢复清单推导，逐一校验，不再依赖 M1.10 固定白名单。 |
| 47 | [#9](https://github.com/deanxizian/MORI/pull/9) | 继续执行前核对全部源输入及前序产物哈希；过期、缺失或失败记录均拒绝。 |
| 48 | [#9](https://github.com/deanxizian/MORI/pull/9) | 验证实际 PNG 大小、SHA256、几何哈希及完整视图集合；仅有清单不算通过。 |
| 49 | [#9](https://github.com/deanxizian/MORI/pull/9) | 失败重试须有更晚成功记录、匹配日志和实际产物哈希；不再只改文字就标成功。 |
| 50 | [#9](https://github.com/deanxizian/MORI/pull/9) | CAD 解释器由 MORI_CAD_PYTHON 或当前 Python 决定，并实际检查导出器直接使用的 OCP 可导入。 |
| 51 | [#10](https://github.com/deanxizian/MORI/pull/10) | 源模型清除四个已定位微小游离体，主壳面片完全保留；STL 导出拒绝 Head_Front 多连通体。 |
| 52 | [#11](https://github.com/deanxizian/MORI/pull/11) | 资产表用 GIT_ZIP_MEMBER 明确原生 PCB 所在 ZIP、成员路径、成员哈希及 ZIP 哈希。 |

## 尚未解决的工程事项

### PR #12 二次审查

`ddfaf9d` 的自动审查完成于 2026-10-07，提出 10 条意见。本次追加处理如下；旧阶段的机械限制继续约束结构设计，当前工作是用户要求的整个仓库审查修复。

- F413/F412：原始 `48fe22aa` 中 `contracts/components.json#/components` 的 `motion_mcu` 已选 WeAct F412RET6；保留匹配这一硬件的构建，并修正仍写 F413 的 `software_profile.json`。没有换板。
- Head_Front：保留单独记录的四个数值碎片清理。它属于本次审查修复，不冒称原 M1.52 两枚螺母改动；主壳的 17,554 个面片逐一保持。没有外形或接口重设计。
- components.json：本次仓库审查按既有 SP3040 和 6806ZZ 选择校正过期说明；原始硬件快照和全部 PCB/原理图/库字节保留。没有宣称新电气设计或制造放行，后续机械设计仍不得擅改硬件源。
- 相机轮询：处理关闭/失联时的 HTTP 失败，丢弃旧帧；真实 Chromium 注入 409/401 各 4 次，没有未处理的 Promise 错误。
- 当前报告：`--core` 同步运行 STEP 导出、交付检查和报告生成；打包核对报告、HTML 及全部相关产物指纹，拒绝旧 PASS。
- 构建输入：仅校验构建清单、明确的当前补充输入和厂家源；不再强制恢复历史报告、A0 参数或旧运行时缓存。
- 原生工程包：先在内存中生成并校验所有新 ZIP，再以临时文件替换。写前保留恢复日志/备份；后续项目或最终清单失败时回滚，中断后重跑先恢复。两个注入故障测试和幂等检查通过。
- 网关凭据：按完整规范化地址（含路径）隔离；旧的仅 origin 凭据不自动迁移，避免发到同域名下另一个机器人。
- 头部禁驱：独立 `torque_enabled` 默认关闭，DISARM/FAULT/释放立即关闭，位置静止不能代表禁驱；STOP_MOTION 保持与故障停机不同。主机测试通过，实体适配器仍未接通。
- 删除重放：跳过数据库已记账的 tombstone，仅实际删除内容时重建索引；正常重启不再重复 VACUUM。

新增网页回归后共 11 项，存储/网关 12 项、归档工具 10 项和 V1 C 核心均通过。首次新 core 流程暴露了 OCP 环境被误要求安装完整 cadquery 的检查错误，已改为检查导出器实际依赖；失败记录保留，不把它计为通过。 后续从 851 文件的 R4 ZIP 独立解压，完整 `run_all.py --core` 八个阶段及再次打包全部通过；本次验证渲染为 128 px / 1 sample，主模型原有的高分辨率图片未替换。当前几何仍为 25 PASS、0 FAIL、9 NOT_TESTED、10 BLOCKED。见 [完整重建结果](review_evidence/round2-core-result.json)。

第 29 项的供应商裁线长度没有被凭空填入；相关表已明确降为端点定义，制造仍 BLOCKED。S01–S08 原编号对应关系也没有原始资料，只能明确未提供。头部舵盘、上部反力夹初装、完整带线闭壳、WeAct E 孔针实物匹配、急停实施、打印强度及实机运行见 [当前状态](CURRENT_STATUS.md)。这些边界继续保留，代码合并不改变它们。

### 追加交付边界检查

对 `2da643c` 的复审提出三条补充意见：报告生成器现在允许无 Git 的独立目录，并避免借用父目录仓库的身份；基线 ZIP 要求完整且唯一的成员集合、全包 CRC 和逐项哈希；机械流水线保存实际命令、输入/脚本指纹、产物指纹和日志到 `pipeline_execution.zip`，打包逐项核验这些执行记录，修改任一脚本后不得沿用旧 PASS。15 项工具回归及原始固件归档 48 项校验通过，完整新流水线八阶段也已通过，执行记录保存在 pipeline_execution.zip。R5 交付包独立解压校验通过；故意修改 validate.py 后被拒绝，恢复原始内容后重新通过。当前几何指纹及全部 21 个 STL 的 SHA256 与前次模型一致，电子细节模型和历史演示无需重复生成。见 [本轮结果](review_evidence/round3-core-result.json) 与 [独立包检查](review_evidence/round3-package-integrity.json)。

### 最后一轮行为与交付检查

`75abb96f` 复审的四项补充已处理：提交八阶段 `pipeline_execution.zip` 与其引用的四个金属轮轴设计文件；两个证据入口统一调用 `project_git`，拒绝继承父仓库身份；同一 CAMERA_MODE 下只更新上传授权，保留目标、观测和 HEAD/BODY 跟随，真正切换模式仍取消旧目标；WebSocket 在初次鉴权、接收命令及后台遥测发现凭据失效时均以 1008 关闭，浏览器清除保存的凭据，普通网络断线继续保留配对。网页 13 项、后端/仿真 57 项、工具 15 项回归通过；新增测试覆盖 HEAD/BODY 双向授权切换、未知与撤销令牌、空闲连接撤销、浏览器重载和正常断线。

从 d7f8379c 干净 Git 检出后，按公开固定来源恢复并核验 529 项输入，通过当前流水线与打包完整性检查，无需为了补缺失执行证据重新构建。普通远端文件完整哈希复核、LFS 对象编号/大小/文件头检查和本地 LFS fsck 均通过。见 [干净检出记录](review_evidence/round4-clean-checkout.json)。

## PR #13：M1.55 交付与恢复复核（2026-10-10）

对 `ac9cae054e` 的六项 P2 意见已落实到代码与交付流程：最终页面生成后再写动画交付哈希；H06 原始数值报告和入壳要求作为独立资料包发布；机械合同同步已完成的 R2 保存后检查；动画脚本与页面生成器按 R2 及匹配证据输出状态，不再恢复旧的裸件装入阻挡提示。实发舵盘、最终锁紧、完整带线装配和强度仍保持未验证。

恢复器在任何写入前检查所有目标和父目录，并拒绝“某个选定文件同时被用作其他文件的目录”。每个 ZIP 只校验和打开一次，成员仍逐项校验并独占发布。新增回归覆盖后置父路径为文件时零写入、包数量恒定的读取次数、并发文件保护、错误哈希的临时文件清理，以及 R2 页面在证据缺失／过期时不得输出通过。25 项工具测试通过。

完整数字交付重新生成；[206 个零件的精确前后对比](review_evidence/M1_55_review_geometry_equivalence.json)无几何、位姿或分类变化。来源保护首次被 Finder 的 `.DS_Store` 变化阻断，修正后仅排除该缓存与 Python 字节码，846 份硬件来源文件继续逐项受保护。初次失败日志与后续实际执行记录均保留在[几何执行包](evidence/M1_55_validation_evidence.zip)。最终哈希、资料恢复及导航核验以[本轮发布记录](review_evidence/M1_55_publication.json)为准；GitHub Review 和合并状态以 [PR #13](https://github.com/deanxizian/MORI/pull/13) 为准。

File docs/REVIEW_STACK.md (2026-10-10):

# PR 审阅顺序

这些 PR 依次叠加，每份 base 是上一层分支。按顺序审阅与合并；本轮按用户授权在复核后合并并清理分支。后续合并时需维护依赖关系：普通 merge 后可将下一份 base 改为 main；如使用 squash/rebase，先重放下游分支，避免重复差异。

| 顺序 | 范围 | PR | base |
|---|---|---|---|
| 1 | 项目规则、许可与归档属性 | [#2](https://github.com/deanxizian/MORI/pull/2) | main |
| 2 | 网页、后端、协议与仿真源码 | [#3](https://github.com/deanxizian/MORI/pull/3) | review/01-foundation |
| 3 | 固件与软件验证工具 | [#4](https://github.com/deanxizian/MORI/pull/4) | review/02-software |
| 4 | 硬件选型、电气契约与接线 | [#5](https://github.com/deanxizian/MORI/pull/5) | review/03-firmware |
| 5 | 四块当前原生 KiCad 项目 | [#6](https://github.com/deanxizian/MORI/pull/6) | review/04-hardware-contracts |
| 6 | 机械参数与正式交接 | [#7](https://github.com/deanxizian/MORI/pull/7) | review/05-native-pcbs |
| 7 | 当前机械构建流程 | [#8](https://github.com/deanxizian/MORI/pull/8) | review/06-mechanical-parameters |
| 8 | 机械检查及展示工具 | [#9](https://github.com/deanxizian/MORI/pull/9) | review/07-mechanical-builders |
| 9 | 当前模型、STL 与装配视频 | [#10](https://github.com/deanxizian/MORI/pull/10) | review/08-mechanical-tools |
| 10 | 资料导航、恢复工具与校验记录 | [#11](https://github.com/deanxizian/MORI/pull/11) | review/09-current-models |
| 11 | 审查修复及组合树复核 | [#12](https://github.com/deanxizian/MORI/pull/12) | review/10-navigation |

修复前的完整资料树位于第 10 层；审查修复在第 11 层中汇总。这些 PR 均已合并，以 `main` 为准，临时审查分支已删除。原 PR #1 由这组拆分取代并关闭；2026-10-07 按用户要求删除剩余的原始归档分支，当时 GitHub 仅保留 `main`。历史资料继续通过 PR #1 引用的固定提交定位，见下方归档说明。

[归档与下载](GITHUB_ARCHIVE.md) · [项目索引](PROJECT_INDEX.md)

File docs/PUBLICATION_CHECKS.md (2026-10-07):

# 拆分发布检查（修复前的历史记录）

以下是拆分阶段原记录；后续修复与重测见 [REVIEW_CLOSURE.md](REVIEW_CLOSURE.md)。

这轮只检查资料拆分及交付，不是新的机器人设计或硬件验证。原始提交为 `48fe22aa75554c9d7bb237e2d2dcacca7f83dde1`；具体结果见 [SPLIT_VALIDATION.json](SPLIT_VALIDATION.json)。

- 594 个收到的源文件、原生 CAD 文本与资产，其 Git blob 与原归档一致；四套工程 ZIP 中全部 242 个原始文件也与原提交逐字节一致；导航、归档属性和恢复工具单独维护。
- 172 个可恢复数据文件已对照原提交验证大小和 SHA256，LFS 数据核对对象指针。
- 23 个当前关键文件在本地验证了完整 SHA256，包括三个 Blender 工程、视频、尺寸源、契约和四套原生 PCB 主文件（PCB 现打包于 ZIP）。
- 新导航中的 91 个本地链接及 77 个固定提交证据链接检查通过。收到的原始源码说明保留原文，内部历史路径可能需要完整归档。
- 恢复工具实际下载一个公开资料文件，重复执行保留原文件；已有不同文件、路径越界、符号链接、损坏下载及并发新建文件的保护检查通过。
- 本地 `git lfs fsck` 通过；Gitleaks 扫描 13 个提交的约 4.75 MB 文本差异，无发现。原生 CAD 的二进制 diff、ZIP 内容和 LFS 载荷不在这次文本扫描范围。GitHub 忽略本地 binary 属性，原 PCB/封装组达到 220,265 行，仍返回 406；已改用保留完整原字节的工程 ZIP，重新核对全部 10 份 PR 后，公开完整 diff 均为 HTTP 200，文件段数与 PR 文件数一致；每份最多 148 个文件、17,349 行新增内容。

- 四个原生工程 ZIP 已从公开地址完整下载并核对 SHA256；三个 Blender 的公开 LFS 对象大小、OID 和前 64 字节检查通过，没有重新完整下载这三个大文件。
- 远端 diff 的精确提交与哈希记录在 JSON 中；随后仅补写记录的文档提交在交付时另行复核。自动代码审查结论不由这些检查代替。

本轮使用 Git 2.54.0、Git LFS 3.8.0、GitHub CLI 2.92.0、Gitleaks 8.30.1。主要检查命令为 `git ls-tree -rz`、`git show`、`git diff --check`、`git lfs fsck`、`gitleaks git --log-opts=main..HEAD`，以及 SHA256／恢复工具行为检查。不会将 GitHub diff 可读、扫描通过或源码完整解释为工程构建、自动代码审查或实物验证通过。

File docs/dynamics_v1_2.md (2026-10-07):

# V1.2 离线动力学检查

状态：SIMULATION / PASS；BENCH、ROBOT / NOT_TESTED。代码在 `simulation/dynamics.py`，结果在 `reports/v1_2/SIMULATED_dynamics_v1_2.json`。它检查符号、延迟和有限控制能力下的失稳/故障路径，不生成实机增益。

模型输入仍是轮轴平移加速度 a（m/s²），**不是 S288 扭矩指令**。正前倾 θ 需要正向 a 来纠偏。刚体小角度模型为：

```
J θ̈ = g H θ − H a − I_head ψ̈
H = m_body h_body + m_head h_head
J = m_body h_body² + m_head h_head² + I_head
```

头部重心假设位于 pitch 轴，ψ 为相对机身的头部 pitch。轨道质量惯量与头部自转惯量分开；头部重心偏离轴、轮胎弹性和电机电气动态未建模。body=1 kg、h_body=0.15 m 等是显式 ASSUMED，绝不是结构称重或最终质量；头部压力工况使用 0.18 kg、0.26 m、0.001 kg·m²，与实机参数文件完全隔离。

控制器依据 body-only 线性方程和指定极点计算：ωn=5 rad/s、ζ=0.8，kp=g+hωn²、kd=2hζωn；所有工况保持同一控制器，未按结果反复“调好”。这是加速度输入的符号检查，不能把这组增益复制到输出 Nm 的固件。

供电能力用 `supply_fraction` 降低可用加速度上限，表示低电/限流导致的能力下降。它没有推导电池端电压、SOC、电流或热模型，不填写未知的 3S 欠压/过压阈值。达到持续饱和或严重倾角时终止仿真并记录故障；这不是机器人能继续站立的承诺。

| 工况 | 验证目的 | 此次结果 |
|---|---|---|
| nominal | 延迟/死区/噪声下正负号 | PASS，模型末端倾角绝对值 <0.01 rad |
| reverse | 错误电机方向 | PASS，识别 SEVERE_TILT |
| delay_120ms | 过大闭环延迟 | PASS，识别 SATURATION |
| wheel_slip | 输出不能变成地面加速度 | PASS，识别 SEVERE_TILT |
| low_supply | 可用输出下降 | PASS，识别 SATURATION |
| head_inertia | 头部质量及惯量改变被控对象 | PASS，数值有限、惯量工况可重放 |
| head_motion | 头部加减速对机身的反作用 | PASS，静止头与摆头产生不同响应；不是稳定性验收 |
| combined | 头部、延迟、供电能力叠加 | PASS，识别 SATURATION |

自动测试另外验证：零供电时不能纠偏、头部反作用双向且确定、同一初倾角下头部惯量改变自由倾倒过程，NaN/Inf/负惯量/非法延迟被拒绝。模型中的416 Hz、2 m/s²与故障阈值仍是旧符号模型的假设，不能作为 STM32 实测频率或新版安全参数。

重放命令：

```sh
.venv/bin/python -m simulation.dynamics --output reports/v1_2/SIMULATED_dynamics_v1_2.json
.venv/bin/python -m pytest simulation/tests/test_dynamics_replay.py -q
```

下一步辨识需要真实轮径/传动比、质量/重心、S288 输出模式及响应、摩擦/回差、头部惯量、功率余量、采样/通信延迟。取得这些证据后才可建立 Nm 输入模型与台架参数版本；不能以本模型替代防摔保护下的整机试验。

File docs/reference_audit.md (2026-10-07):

# 参考与依赖审查

实际参考 commit、源文件 SHA256、取得日期在 `refs/sources.lock.json`。首次 GitHub API 受限的记录保留，
随后用公开仓库 Git commit 与 raw 文件取得锁定资料。参考仓库归档没有直接加入应用主循环。
主工程为 MORI 自有 motion / interaction / backend；只移植 bloub 双眼所需函数，其他模块通过明确接口适配。

| 来源 | 阅读事实与决策 | 编译/许可边界 |
|---|---|---|
| rig_omni `main/boards/hover/xgo.cc` | `xgo_control()` 实际走 `temp_u=-Kx`；前面的多 PID 路径被注释。运行状态有直立后自动恢复逻辑，MORI不继承。`wheel_x`写死0.06m、1024计数；姿态用deg；tor先转short再同步串口发给多个ID，未见N·m标定。三次2ms延迟加处理/串口，注释Ts≈6ms不是实测。yaw-q_head与头补偿按其结构，不能移植到身体IMU | 未发现仓库顶层 LICENSE，**不复制其实现**。只记录分析。保留原有有刷台架驱动，不把FOC串口当PWM |
| StackChan-BSP `servo.h/cpp` | 有限位、动画与反馈/估计接口。默认 `setAutoTorqueReleaseEnabled` 为true，静止200ms后可能卸扭矩；MORI双轴重力负载不能照搬。MORI采用SI限速/限加速度轨迹，静止保持目标 | MIT；参考，不复制弹簧主循环。原 stack-chan 仓库 Apache-2.0，亦未整体fork |
| bloub `src/bot/face.ts/math.ts` | 保留原文件对照；抽取正交投影、眨眼、视线漂移。MORI新增8状态、从当前合成帧中断切换、RGB565圆形裁切和皮肤接口。原眨眼表900s结束，MORI以905s周期复用眨眼表，视线噪声时钟不重置 | MIT (Jérémy Perret 2026)，C与TS逐文件通知。仅代码许可，不是Grok/xAI形象商业授权 |
| 小智 ESP32 当前参考 | 锁定主线的依赖要求 IDF≥6.0.1、ESP-SR2.4.7、LVGL~9.5，不能硬塞进5.5.2。采用协议v1 hello/listen/abort/Opus会话与适配器，禁MCP执行工具 | MIT；未复制整套Application。服务端参考 xinnan-tech 为社区兼容实现，不宣称官方云源码 |
| ESP-SR | 本机实际编译锁定2.2.0。`MR`为mic/reference两个声道的AFE输入契约；实际参考须来自DAC已播放采样。模型分区已参与构建，自定义词未提供 | Espressif MIT限制用于Espressif产品。现成测试唤醒候选“你好小智”与MORI自定义训练/费用/模型条款需分别核验。误触发/漏检、远场、AEC效果NOT_TESTED |
| LVGL | 实际依赖9.2.2，Canvas RGB565适配。未把SVG mask直接交给驱动；逐像素胶囊几何与圆形安全区先合成 | MIT。240/360主机渲染测量不代表ESP32帧率，不承诺60fps |
| esp32-camera / ESP-WHO | 前者实际编译2.0.16，初始化需明确camera_config与验证门。ESP-WHO仅参考候选；未复制其全应用或声称轻量人脸已经跑在目标板上 | 相机驱动Apache-2.0，WHO Espressif MIT；模块引脚/内存/吞吐未实测 |

工具链：两个域均固定 ESP-IDF5.5.2，各自 dependencies.lock。交互解析到 ESP-DSP1.6.0、dl_fft0.7.0、
esp_jpeg1.3.1（完整哈希见锁文件）。默认门全部n，单独编译门分支验证不等于允许烧录。

网页 Vue3.5.13/TS5.8.3/Vite6.3.5，Capacitor7.2.0/App7.0.1。依赖全由 pnpm-lock.yaml 锁定。
原生 iOS 用 SPM exact7.2.0 与 Package.resolved commit；Xcode27要求最低目标15与UIScene，已适配。
SPM下载在本机挂起时，只对本地生成缓存改为已经 SHA256 核对的同版官方xcframework，应用锁文件未改版本。
原生 Android 模板 Gradle8.11.1（校验和锁定）需JDK21/SDK35；本机缺Java，实际构建BLOCKED。

Python直接依赖与解析依赖分别在 backend/requirements.in、requirements.lock；PyAV14.4.0在此平台没有可用wheel，
构建缺pkg-config/FFmpeg，真实失败日志保留，明确改锁有arm64 wheel的16.0.1。Opus编码/解码回环已通过。
容器 Python/Caddy 精确 tag + registry digest 已核对；本机无Docker，Compose启动NOT_TESTED。
第三方完整许可放 docs/licenses 和包自带文件；将来商业分发还须审查模型权重与FFmpeg轮子实际组件，不以本文件代替权利许可。

Apple生命周期依据：[UIKit 场景迁移](https://developer.apple.com/documentation/technotes/tn3187-migrating-to-the-uikit-scene-based-life-cycle)。
相机依赖依据：[Espressif 2.0.16](https://components.espressif.com/components/espressif/esp32-camera/versions/2.0.16)。

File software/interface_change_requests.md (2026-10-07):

# 软件接口变更单 SW-0.4（对 HW-SW-0.4，2026-09-21）

> 本文件为累积历史。当前V1.2变更见文末ICR-019～024；下述2S阈值/GPIO/驱动和方向仅适用各自旧版本，不定义V1.2。当前软件入口为根 README_SOFTWARE_V1_2.md。

所有改动仅在 software/；候选模块台架接口，PROTOTYPE / UNVALIDATED。硬件任务合并前须审阅。所有实物验证 NOT_TESTED。本任务未修改硬件目录与机械定义；上游快照由并行硬件任务更新，见文末版本差异。

| ID | 动机 / 原接口 → 新接口 | 受影响文件（software/firmware_work/firmware/ 下） | 兼容 / 决定 |
|---|---|---|---|
| ICR-001（已废止，见ICR-012） | 历史0.2提示词指定#5216：曾将979.616改为1204.44 counts/rev；该变更只适用于旧候选，不适用于0.4的#4863。当前恢复0.4规定的979.616 | main/board.h别名、include/mori_io.h唯一换算源、测试/元数据/文档 | 不向硬件回写旧提案；PCNT仍2单元×2通道，48 CPR已含x4，不再乘4。旧数据保留原比例 |
| ICR-002 | 原始 IMU 轴直接作控制轴、符号藏于 board.h → 可替换刚体旋转矩阵及四个 ±1 符号，默认矩阵 identity（未核验），符号保持 +1/-1/+1/-1 | main/mount_config.h, sensors.c, encoders.c, motor.c; include/mori_io.h | GPIO/±2g/±500°/s 不变；CONFIG_MORI_AXES_VERIFIED 默认 n，未签字拒绝 confirm_signs 和平衡解锁；六面/俯仰/方向记录后修改配置 |
| ICR-003 | 无请求 ID、sscanf 宽松解析、仅异步 rejected 标志 → MORI/1 文本协议，支持 @ID 前缀与每命令 ACK/REJECT，严格字段/有限数/溢出/行截断检查；info/status 查询 | main/main.c, components/mori_core/mori_protocol.c, mori_runtime.c | 原命令拼写保留；无前缀标 ID=0，建议主机用唯一非零 ID。新遥测带 DATA 前缀与明确列头；主机支持基线 CSV 只读回放 |
| ICR-004 | 原 READY 不锁存传感器失败、重复样本推进校准、首因被覆盖 → 就绪/校准失健康锁存 FAULT、严格新时间戳、首因保留；队列溢出 MF_QUEUE=12；配置非法 MF_CONFIG=13 | mori_core.c/h, mori_runtime.c/h | 原故障 0–11 保持；必须人工 ack→重新校准→显式解锁；溢出时清退待处理命令，不能靠已排队 ack 重启 |
| ICR-005 | 2404 us 计算保护阈值 → 完成帧计算+传输预算 1800 us；输出前后检查，超预算锁存 MF_TIMING；8 ms 仅缺样后备；健康完整帧才翻转心跳 | mori_runtime.c, main/main.c | GPIO42 不变，不用自由 PWM 喂狗；外部链路超时和实际波形须硬件决定并实测；PWM寄存器提交不等于物理生效 |
| ICR-006 | 隐式覆盖日志无丢弃数 → 分离采样遗漏、遥测队列丢弃、命令队列溢出、回复丢弃计数；低优先级可导出分段时间、原始及控制系IMU、独立左右速度和健康标志 | mori_runtime.c/h, main/main.c | 固定容量队列；串口115200不足以全量416Hz文本输出，默认每40帧遥测，完整帧最大值/直方图独立统计；不可把抽样分位数当全帧 |
| ICR-007 | 屏幕渲染固定240无裁切 → 分辨率独立 RGB565 圆形渲染器、无屏及主机 PPM 模拟后端；GC9A01适配仍只支持240×240 SPI | mori_ui.c/h, main/display.c | 不改引脚、不将RGB并行屏当SPI；最终Ø60面板待硬件选型 |
| ICR-008 | 头部轨迹在实时控制任务内 → 低优先级20ms任务；默认无PWM，显式验证开关后只接收±50°；故障/失鲜停PWM。转向目标增加有限加速度，姿态纠偏无全局斜率 | mori_ui.c/h, main/main.c | 头映射1500−12.963×deg及50Hz保持；速度上限30°/s、加速度60°/s²为软件试验起点；head失效禁用最长一个任务周期加调度延迟须测。新转向目标斜率0.4 duty/s待辨识 |

电池阈值保持：8.4 V标称满充，6.8告警/禁止新解锁，6.6请求支撑，6.0严重欠压禁用；既有过压8.65 V、|母线电流|>1.30 A、温度0–65°C、倾倒20°、输出0.65、饱和200ms保留为未测的软件验证起点。不可替代BMS/保险/回灌钳位。任何阈值修改需新变更单。

ICR-009 — 台架授权仍固定在 arm 时刻后200ms，软件提前8ms撤销（有效目标窗口约192ms），给已受限控制帧间隔和提交留余量。原实现仅在到达200ms后的帧撤销，可能晚一个周期。影响 mori_core.h/c、mori_runtime.c；重复 duty/arm 不延长。该保守收紧不改变PWM/电气接口。CPU阻塞/中断延迟的物理截止仍由外部安全链保障，示波器证明最大通电时长<=200ms之前实物验收 NOT_TESTED。

ICR-010 — 本地IDF v5.5.2的ledc_set_duty_and_update要求先安装fade service（esp_driver_ledc/src/ledc.c:1307、1579）。基线缺少该初始化且忽略返回错误。已先用遵守该API契约的模拟驱动复现FAIL，再在motor_init禁用阶段安装service并逐通道预建资源；提交失败保持ARM低并锁存driver失效，须复位并重新检查。头部提交失败/任务失鲜保持该目标revision禁用，需新显式head命令。影响main/motor.c、main.c、peripherals.h、mori_ui；不引入输出斜坡、不改变GPIO/PWM频率或方向；该修复的实机PWM行为仍NOT_TESTED。

## 版本追溯与已解决的接口冲突

最初用户0.2提示词指定#5216，实际解压时上游已到0.3；原始版本、21成员SHA和当时构建结果仍见`reports/baseline_integrity.json`。上一交付按明确的0.2要求保留1204.44，报告其对0.4兼容性FAIL。本次用户明确要求按HW-SW-0.4继续并读取并行提示，已据此解决接口选择；原发布报告在`reports/pre_hw04_merge/`，未改写历史证据。当前接口一致性以重新构建、测试和严格上游校验结果为准，实物仍NOT_TESTED。

ICR-011 — BENCH原输出结构整体赋值会抹掉低电告警/支撑请求标志；已通过6.5V台架模拟先复现FAIL，再改为只设置轮输出字段，保留低电标志。影响mori_core.c与测试；6.8/6.6/6.0V阈值完全不变，台架授权不能延长。

## ICR-012 — 依本次用户指令合并 HW-SW-0.4

动机：采用2026-09-21硬件交接0.4及同目录并行更新说明；保留软件安全修复，撤回ICR-001旧电机提案。依据副本在`reference_sources/HW-SW-0.4_*`；23个快照成员及受保护输入SHA见`reports/hw04_adoption.json`。

| 原接口 → 新接口 | 受影响software文件 | 兼容策略 / 状态 |
|---|---|---|
| #5216、12×100.37=1204.44 → #4863、48×精确20.4086667=979.616 counts/rev；m/count 0.000247792585842 → 0.000304661522567 | firmware_work/firmware/components/mori_core/include/mori_io.h、mori_io.c（实时测速仍使用float）；tests/test_engine.c、test_baseline_interface.py、test_hw04_interface.py | CPR/齿比/1:1皮带仅在一个运行时头文件定义；独立物理换算示例验证8帧测速和禁止再次x4。没有改PCNT配置/候选方向符号 |
| INFO SW-0.3/需求0.2/两位计数小数 → SW-0.4/需求与接口快照0.4/三位计数小数，origin=0.3保留 | firmware_work/firmware/main/main.c、tools/SIMULATED_device.c、共用mori_io.h；采集/回放元数据测试 | MORI/1及CSV列不变，新增origin字段兼容忽略；旧记录SHA不变，不重标版本或重算旧速度；生成SIMULATED_hw04_*新记录 |
| USB供电说明缺失 → 拔整个J12，保留J14，编码器DEVKIT_5V经LVC14转换；J4/J5自定义XH6 | firmware_work/wiring.csv、pinmap.csv（GPIO内容未变）、docs/hw_sw_0_4.md、debug_manual.md、protocol.md、记录模板 | 逐字对照0.4镜像；不改硬件文件，不能据软件测试判电气通过。USB模式禁Wi-Fi，预算<500mA仍待测 |
| 模型左右名称含糊 → control left=模型R/X正、right=模型L | main/mount_config.h注释、direction_checks.md、调试手册、测量模板 | 不翻转任何已存符号或矩阵，两个A/B同时反相保持相序，实际符号仍须测量 |
| ADC/过压可能被误认作所有母线尖峰 → 明确ADC=VMAIN；VM_MOTOR独立示波器观测；R14=25.5k0.1%、R15=10k0.1%、R16=2.2M1% | docs/hw_sw_0_4.md、debug_manual.md、realtime.md、记录模板 | 软件8.65V不变；8.73–9.04V仅钳位开启估算。电气热/回灌NOT_TESTED |
| 功率门文本按旧阶段编号 → 独立急停/看门狗/限流/钳位资格后才允许台架 | main/Kconfig.projbuild、debug_manual.md | 只同步说明，不解开任何编译门；头±50°、IMU量程、6.8/6.6/6.0V及全部故障语义保持 |

验证：先运行新增0.4行为测试记录4项FAIL，再合并并复测；本次完整构建/安全/协议/模拟及严格交接检查的真实结果统一见`reports/final_validation.json`。旧状态机/运行时/协议/驱动等关键源文件哈希保留核验，原有回归不删减。此次软件接口对齐不冻结采购、装机BOM或赋予实物签字。

## ICR-013 — MORI V1 目录与安全配置分离（2026-09-21）

动机：用户新提供 MORI_SPEC_V1.md，四执行器/双MCU/相机取代 A0 三执行器与单MCU。
旧接口：software/firmware_work/firmware 是唯一台架固件，直接使用HW-SW-0.4候选GPIO。
新接口：**同一份源迁移**到 firmware/motion，旧路径为 ../../firmware/motion 符号链接；
新增 CONFIG_MORI_LEGACY_BENCH_PROFILE 默认n。V1默认只运行禁驱核心，不初始化未冻结GPIO；
显式旧台架profile才进入原主路径，功率/平衡/头/轴验证门仍默认n，增益0。
影响：firmware/motion/main/main.c（原入口重命名）、v1_main.c、Kconfig/CMake、software旧路径及文档。
兼容策略：原主机/模拟HAL/串口工具/CSV与163+2211+22+10断言保留，迁移前源哈希保存在reports/v1/motion_migration_hashes.json。
没有改 hardware/、原GPIO/方向/CPR/阈值。HW0.5隔离与功率改装仍不等于V1装机签字。

## ICR-014 — MORI/2、SI与运动租约

动机：网络/双客户端/自主行为不能复用无会话文本命令。
旧：MORI/1文本与500ms目标撤销，差动值为归一化PWM；新：MORI/2完整命令ID/来源/权限/单调时钟依据/
300ms运动租约/独立结果状态，加本地CRC帧、序号与MCU启动会话。协议见contracts/README.md。
影响：contracts/*（不含机械文件）、firmware/motion/components/mori_v1、backend、simulation、apps。
兼容：不自动转换两协议；保留旧工具，非零yaw rad/s在旧有刷接口映射未测前明确拒绝。正常STOP与FAULT/DISARM分离；
语音/表情/相机配置不依赖运动租约，但经过独立权限检查。运动/头部/维护仍需本机门和显式授权。

## ICR-015 — V1坐标与双轴头部

动机：V1机械前向+Y，与A0前向-Y冲突，且头增加pitch。
旧：A0 control=(-Y,+X,+Z)、单yaw GPIO41/名义−1.75传动；新：V1 control=(+Y,−X,+Z)，头yaw正左、pitch正上、身体pitch正前倾。
头部SI目标yaw±60°、pitch−20..+25°，软件假设速度0.52rad/s、加速度1.05rad/s²；各轴含零点、符号、限位、反馈/估计标记，静止不自动卸扭矩。
影响：contracts/coordinates.md、mori_v1、simulation/vision.py、控制台；旧mount_config属于旧profile，数值未翻转。
兼容：V1新HAL未绑定旧矩阵/编码器/舵机PWM；硬件须签字真实两轴舵机、齿比/脉宽、支撑负载与线缆扭矩后再提供adapter。
视觉把采集时相机射线经头角/机身姿态转世界，再转当前机身；内外参目前只用显式模拟假设。

## ICR-016 — 交互域接口、显示与隐私

旧：GC9A01单域台架显示、无相机/音频。新：独立ESP-IDF5.5.2交互工程，LVGL9.2.2/ESP-SR2.2.0/esp32-camera2.0.16锁定。
双眼采用bloub参考函数+C移植与MORI8状态，可变分辨率RGB565/Canvas与圆形裁切；原小屏不是最终机械面板。
音频16kHz mono麦克风与已播放reference；小智v1协议输入Opus16kHz/60ms，输出24kHz，半双工，设备播放时间独立记录。
相机OFF/SNAPSHOT/TRACKING，按需上传须明确许可；模拟输入为确定像素夹具，非随机检测框。
影响：firmware/interaction、backend音频/视觉适配、apps预览；新GPIO/串口速率/音频codec/屏幕总线/按钮引脚均待硬件任务决定。
兼容：本次只在独立编译配置中核验打开分支，交付默认配置全关闭；未发送实机解锁、烧录或远程部署命令。

## ICR-017 — 后端与App

新增单用户SQLite作用域记忆、来源/冲突/确认/删除清单、认证凭证、预算上限、TLS/WSS部署文件；
Vue界面与Capacitor iOS/Android工程。凭证不得将云API主密钥放入网页/固件。
iOS因本机Xcode27最低目标调整到15、补UIScene后台停止续租；Android工程需JDK21/SDK35。
上述无GPIO变更，所有物理执行器/自主能力继续BLOCKED，硬件任务无需合并Web或服务器代码到实时主循环。

2026-09-21后续用户范围调整：当前只需要网页，暂停App开发/验收。保留已有apps/mobile工程及历史构建证据；CI默认不运行移动端构建。该调整不改变V1机械、电气、协议或安全门。

## ICR-018 — 网页播放观测与打断回执

动机：云生成完成、收到打断请求都不能代表扬声器已停止。原接口只有playback开始/结束；新接口增加voice_interrupt.command_ids、interrupt_ack与voice_metrics事件。
影响：backend/mori/app.py、apps/console/src/client.ts、backend/tests/test_audio.py。
兼容：MORI/2命令字段不变；这些是经认证会话中、绑定原command_id所有者的观测事件，不能产生运动命令。
GATEWAY_MONOTONIC_MS时间只表示服务器收到HOST_WEB_AUDIO回执的时刻，包含网络延迟，不冒充设备DAC/声学延迟；物理播放时序仍NOT_TESTED。

## ICR-019 — V1.2 STM32与执行器（2026-09-22）

动机：按新用户规格迁移，保留旧回归。
原接口：ESP32-S3、有刷PWM/PCNT或未释放FOC、PWM头部。新接口：STM32F413、S2886Mbps独立轮总线、SCS0009独立头总线、ICM42688-P SPI/DRDY。
影响：firmware/motion/CMakeLists.txt、v1_2/、tools/build-*、tests、CI、contracts/software_profile.json。
兼容：旧源不删、旧路径符号链接保留；legacy-motion显式编译旧工程；新的参数与门控不引用旧GPIO/CPR/PWM/2S阈值。S28820/26字节按原厂C显式收发；文档vol宽度、Python signed/round/负pos冲突提交硬件抓包确认。6Mbps候选96MHz仅算术证明，板时钟/收发器未实现。模式0不当作自由卸力，驱动禁用需要独立物理链。

## ICR-020 — 参数、测量与新硬件契约

动机：未知测量不能以模拟0或旧阈值冒充。
原接口：MORI/2既有JSON状态；新接口保持命令与CRC线格式，新增software_version、parameter_version、hardware_profile、physical_release、sensors分组valid/null。
影响：contracts/profile.py/software_profile.json、simulation/device.py、apps/console、reports/decisions/ADR-SW12-001.md。
兼容：旧客户端可忽略新增字段；sensors仅实测后valid，模拟头估计独立。V1.2-H0.1硬件现已采用MORI/2长度/CRC；旧CRC16冲突已不适用。板间baud仍null，S2886Mbps不能代替板间速率。新电池保护阈值null，增益/扭矩上限0；请求硬件提供电源/过压/回灌/测量链。几何/电气文件由并行任务更新，软件只读并记录版本，未覆盖。

## ICR-021 — 微雪交互、ST77916与音频

动机：新SKU33700/35079取代未冻结旧面板/板卡。
原接口：camera2.0.16、8MB构建、240×240无屏帧缓冲；新接口：camera2.1.4、16MB、360×360；新增ST77916 1.0.1 QSPI、codec1.5.4和CH32 1.0.1，保留IDF5.5.2/LVGL9.2.2/ESP-SR2.2.0并实际重编译。
影响：firmware/interaction/main/board_v12.*、main.c、idf_component.yml、dependencies.lock、sdkconfig.defaults/v1_2。
兼容：升级前锁/config归档；默认物理门仍n，接口接收硬件签字配置，无猜测GPIO/FPC。请求确认初始化序列、GPIO/CH32 reset/backlight、FFC物理方向/16–18脚、QSPI电平/供电；TE不可用。请求音频PCM槽、时钟、模拟参考路由/延迟核验，现有软件MR参考不可当作板上AEC通过。

## ICR-022 — 头部、跟随与证据

动机：实测头角缺失会破坏相机→机身变换；到达目标时速度突变违反加速度约束。
原接口：独立轴限幅/估计角；新接口：SCS反馈有效性、标定后SI、联合reachable回调、离散制动轨迹；模拟头反馈丢失取消跟随，健康本地平衡继续。
影响：motion/v1_2/sensors.c、test_motion.c、simulation/device.py、test_v1_2.py、docs。
兼容：机械yaw/pitch范围保留，但不能替代联合包络；菱形联合区域是测试夹具，实机未装入假区域。已保留头轨迹FAIL→PASS日志。请求机械/硬件交付联合区域、零点/比例/方向/限位、负载误差与温度门槛。App按用户要求继续暂停；HOST_TEST/SIMULATION通过不授权BENCH/ROBOT。

## ICR-023 — 相机首帧等待与版本统一

动机：浏览器测试发现TRACKING启用到首帧之间返回409 NO_FRAME，形成控制台错误；/health仍报告旧软件版本。
原接口：首帧未到HTTP409；新接口：已授权且相机开启、但帧未到时HTTP204+WAITING_FOR_FRAME，网页等待下一次有界轮询，不生成空图片。相机OFF仍409、未授权401/403，上传/控制权限不变。/health和遥测共用software_profile版本。
影响：backend/mori/app.py、apps/console/src/App.vue、simulation/tests/test_v1_2.py、浏览器测试。
兼容：MORI/2与UART没有变化；网页和服务器同步更新，旧客户端需处理204无正文。保留HTTP首帧及版本FAIL→PASS记录，不忽略浏览器错误来让测试通过。

## ICR-024 — 离线模型的供电能力与头部惯量

动机：原符号模型只有延迟/噪声/死区/轮滑，不能覆盖V1.2的双轴头部扰动与供电余量下降。
原接口：body-only加速度输入模型；新接口：可选供电能力比例、头部质量/高度/自转惯量及有界pitch运动，输出惯量、重力矩系数和头部反作用；输入默认值保留原模型，输出仍标SIMULATION。
影响：simulation/dynamics.py、tests/test_dynamics_replay.py、docs/dynamics_v1_2.md。
兼容：不改变固件、GPIO、真实电池阈值或控制参数；加速度不是S288 Nm，不能复制模型增益。新工况结果另存SIMULATED_dynamics_v1_2.json，旧报告保留。

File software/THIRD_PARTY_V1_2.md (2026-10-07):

# V1.2 第三方来源与版本

完整commit和许可文件SHA256：`software/references_v1_2.lock.json`；保留V1来源 `refs/sources.lock.json` 与根 `THIRD_PARTY_NOTICES.md`。这里描述采用的版本，不声称它们是所有上游的最新版。

| MORI文件/构建内容 | 上游与采用文件 | 用法 / 许可 |
|---|---|---|
| motion/v1_2/s288.c、simulation/s288_replay.py | [Unitree digital_servo](https://github.com/unitreerobotics/digital_servo/tree/75c1ed63579dc7bb759e2990bd4b804c11b57daf) App/protocol.h/.c、crc_ccitt.h、specs/protocol.md、python/servo_demo.py | 显式独立序列化；差分测试编译原厂C。README限定非商业研究/教育/DIY，商业大批量生产需原厂正式授权；不改标MIT、不宣称商业发布许可完备 |
| motion/v1_2/sensors.c SCS部分 | [FTServo_Arduino](https://github.com/ftservo/FTServo_Arduino/tree/64922cda46e56b21b8c1d9e830d936a1941645ae) src/SCSCL.cpp/.h、SCS.cpp | 按寄存器/字节序独立解析，参考MIT，©2024 ftservo |
| STM32 startup/system/device headers | ST cmsis-device-f4 v2.6.10，commit5f41fb29d22773896c780052bf61e47fc924d524 | 原文件编译/包含；Apache-2.0 |
| STM32 HAL system/RCC/GPIO/DMA/UART/SPI | ST stm32f4xx-hal-driver v1.8.3，commitc2e1406d7ea4b73aa42b98ddeb75a8670b1a5a16 | 原文件编译；BSD-3-Clause；没有复制Unitree整套STM32应用 |
| Cortex-M4 core header | ARM CMSIS_5 tag5.9.0，commit2b7495b8535bdcb306dac29b9ded4cfb679d7e5c | 原文件包含；Apache-2.0 |
| interaction/main/board_v12.c | [微雪CAM官方例程](https://github.com/waveshareteam/ESP32-S3-CAM-OVxxxx/tree/72af9302030bb6f018d5c21b1225005481e09fda) ESP-IDF-v5.5.1/04_dvp_camera_display BSP header/codec初始化参考 | MORI门控API适配；Apache-2.0参考；未复制演示main/固定引脚/整套GUI |
| interaction/managed_components | esp32-camera2.1.4、esp_lcd_st77916 1.0.1、esp_codec_dev1.5.4、custom_io_expander_ch32v003 1.0.1及锁定依赖 | 原组件，许可随包保留；主要Apache-2.0，完整依赖SHA见dependencies.lock |
| 两端双眼C/TS | 原bloub参考与MORI8状态映射 | V1已保留MIT通知；代码许可不授予xAI形象/商标权；皮肤可替换 |
| ESP-SR2.2.0/LVGL9.2.2/小智兼容协议 | 原V1锁文件与通知 | 未拼接三套应用main；ESP-SR特定许可、唤醒模型权利按原文件保留 |

原厂资料：[S288产品页](https://www.unitree.com/mobile/DigitalServo/)标称0.6Nm为反向工况最大/堵转，不能当连续扭矩；[TDK ICM42688-P v1.6](https://product.tdk.com/system/files/dam/doc/product/sensor/mortion-inertial/imu/data_sheet/ds-000347-icm-42688-p-v1.6.pdf)用于WHO/burst/量程核对；[ST77916 1.0.1](https://components.espressif.com/components/espressif/esp_lcd_st77916/versions/1.0.1/readme)和[codec1.5.4](https://components.espressif.com/components/espressif/esp_codec_dev/versions/1.5.4/readme)在本SDK中实际编译。组件可编译不证明板上线路/并发/实时性。

Arm工具链原厂下载并校验SHA256，记录在 reports/v1_2/arm_toolchain.json；执行版本14.2.1（14.2.Rel1发布）。未改用无界latest。

参考仓库按锁文件下载在refs/v1_2，.gitignore不默认把整个参考仓库纳入MORI分发。未来对外发布/销售需复核采用文件与模型/形象的实际权利；本轮不发布或代签授权。

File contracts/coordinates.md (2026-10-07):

# V1坐标与单位

权威机械定义为config/geometry.json和contracts/mechanical_interfaces.json，本文件只定义转换。A0的前方−Y及Wheel_R=left关系不能用于V1。

V1机械/机身M：X右、Y前、Z上；SI控制C：x前、y左、z上；C=(M.Y,-M.X,M.Z)，det=+1。控制left是机械X负侧。机身正前倾为机械−X旋转、控制+y旋转。头yaw正向左=机械+Z；头pitch抬头=机械+X=控制−y，与正机身前倾符号相反。

相机光学O：x右、y下、z前；零位转成控制C=(O.z,-O.x,-O.y)。先按头pitch绕控制−y旋转，再yaw绕控制+z，再乘机身姿态。相机安装偏置与内参来自标定，初始只使用明确标为SIMULATED的假设FOV；估计头角不得标成传感器反馈。屏幕注视x右/y下，与机械头角独立。

所有控制长度m、角度rad、速度m/s和rad/s。UI的mm/deg须转换。时间戳为设备单调ms，采样/完成/到达分开。跨机时钟不能直接相减：命令回显最新设备basis_device_ms，设备计算保守有效期；视觉回传原capture_id，由本地保存的采集单调时间判年龄，拒绝未知ID和过期帧。

视觉实现补充：目标射线先按采集时刻的头 yaw/pitch 与机身 pitch/yaw 转到世界，
再按当前机身姿态反变换到当前机身，以生成头部目标与底盘转向误差。
`target_angles` 的两个机身姿态不可混用。相机内参 fx=fy=1.2（归一化图像单位）
仅为模拟夹具假设；零点、真实内外参、头反馈和里程漂移均须实测后替换。

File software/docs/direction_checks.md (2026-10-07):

# 坐标、编码器与控制符号离线核验

机械坐标来自根params.json/derived.json，不建立第二套机械定义。Blender前方−Y，控制右手系x前、y左、z上：`control=(-Blender_Y, Blender_X, Blender_Z)`。控制left=Blender Wheel_R/Motor_R（X正），control right=模型L（X负）；线束按控制左右标记。**这不等于IMU原始轴的安装矩阵**。安装矩阵R在`firmware_work/firmware/main/mount_config.h`，当前identity仅未验证占位；输出及编码器符号保持交接的左+1/右−1。每次更改必须加接口变更单，重新编译并保存image SHA。

编码器DEVKIT_5V供电，原始A/B约0–5V，先经3.3V供电的SN74LVC14AD再入MCU。两路同时反相不改变相序，不能据此签字方向。USB逻辑供电须拔整个J12、保留J14，具体线序见hw_sw_0_4.md。

## 不出力的测量

1. 功率级禁用、头PWM禁用、刚性固定IMU。在六个姿态分别让控制+x/−x/+y/−y/+z/−z竖直向上，每面静止记录原始三轴加速度至少2.5秒，保留原始CSV，剔除人为晃动须有记录。上指轴的加速度计比力应约+g。检查模长与偏置，不只看pitch。
2. 求raw→control的**正交且det=+1**矩阵；反射矩阵被软件拒绝。±轴交换可以是有符号置换，斜装需要完整旋转。不得按丝印直接签字。更新配置后重复六面，不改变±2g与±500°/s换算。
3. 手扶机身向前倾：顶部朝控制+x。`pitch=atan2(-ax,az)>0`，控制gyro-y>0。手动回正反号。实际方向与理论有一处不符都停止；不能在PD符号上补错来掩盖R错误。
4. 轮驱动供电隔离、逻辑及编码器供电有效时，手动转每个独立轮轴，让接地点对应向前滚动，记录原始计数变化和带轮/电机方向。两侧应用encoder_sign后均正。48计数已含A/B全部边沿x4；精确齿比22³×23/(12×10³)，输出轴979.616计数/转。轮周长/计数=0.000304661522567m，1:1皮带仅暂定。慢速速度用8帧累计计数/实际累计时间（约19.2ms）；一计数量化约0.01584m/s，不是416Hz单帧高精度测速。
5. 功率级核验完成后才悬空单轮≤12%/≤200ms测试。正逻辑输出应使该轮向前滚动，对应的编码器速度应正。保留左右视频及原始记录；分别调整motor_sign或encoder_sign，禁止两者一起猜着改。冻结不动的编码器在静止时无法与断线区分；当前驱动>20%且速度<0.004m/s持续200ms才判异常，台架≤12%不能靠它证明编码器接线健康。

复制`config/mount_measurements.template.json`到有日期的测量记录，填写六面均值、前倾原始gyro、左右手转计数、输出观察和操作人/原始文件/固件SHA。运行：

```sh
python3 software/tools/check_mount.py software/reports/实际测量记录.json
```

该工具只检查数值一致性（六面向量误差暂取≤0.35m/s²，手动gyro-y>0.05rad/s、交叉轴<25%）；不判定真实仪器来源，不写固件，不自动开启axes或signs。上述容差是软件核验起点，须与实际传感器标定协调。记录仍须人审，随后才允许设置axes验证门及显式confirm_signs。

## 唯一输出结构

速度目标先限加速度0.2m/s²；慢速速度误差`ve=v_ref−(vL+vR)/2`经小增益和积分生成限幅±5°的theta_ref。姿态PD是唯一公共力矩：

`u_raw=kp*(pitch−theta_ref)+kd*(gyro_y−bias)`。

公共输出限制±0.65，差动只能使用`0.65−|u|`的剩余余量，`uL=u−yaw, uR=u+yaw`。yaw输入是占空比分量，目标斜率0.4 duty/s；公共姿态纠偏无全局慢斜率。没有另一路轮速PID叠加。积分在输出/倾角饱和时冻结并限幅；持续饱和会锁存故障。增益默认0，协议的允许范围是拒绝异常输入的边界，不是调参建议。

物理符号推理：小角倒立摆有`theta_ddot≈g/l*theta−a_wheel/l`。正前倾需要轮子向前加速，将接地点追到重心下面；反向输出会放大倾倒。正速度误差要求正倾角参考，直立时初始负力矩使轮子后移以建立前倾，随后姿态反馈追上。`tools/check_control_signs.py`用假设长度0.15m只验证这个符号关系，**没有使用真实MORI质量/惯量，也没有证明闭环稳定或调好增益**。

头部外啮合8:14，名义舵机角=−1.75×头角，pulse=1500−12.962963×头角(us)。±50°软件初限约852–2148us，仅名义映射；初次中心/方向/可用范围必须拆传动用独立受控测试源核验并签字。未核验固件保持无PWM，不能为了找中绕过head门。装回传动从±10°开始，逐步检查线缆、齿隙、阻力，不假定壳体±60°机械目标已经可用。

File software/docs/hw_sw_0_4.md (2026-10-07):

# HW-SW-0.4 台架接口对照（2026-09-21）

依据同日硬件交接、并行更新提示、pinmap/wiring和manifest的已封存副本；软件合并记录为ICR-012。所有实物、电气、扭矩、热及自由平衡验证 **NOT_TESTED**。这些值不构成装机BOM冻结。

| 项目 | 当前候选接口 | 软件/实测边界 |
|---|---|---|
| 轮电机 | Pololu #4863 25D MP12V；48 CPR已含x4；齿比22³×23/(12×10³)=20.4086667… | 2S驱动，保留0.39Ω限流；约1kg是预算，扭矩/热余量未测 |
| 轮计数 | 979.616 counts/rev；1:1候选皮带；Ø95轮；m/count≈0.000304661522567 | 8帧计数/实际时间测速；有效周长、实际齿数/弹性/齿隙待测；不再乘4 |
| 编码器供电/电平 | 选DEVKIT_5V；四条原始A/B经3.3V供电SN74LVC14AD（输入容忍5.5V） | 不能5V直入ESP32。A/B同时反相保持相序；初始符号仍未验证 |
| 控制左右 | left=Blender Wheel_R/Motor_R（X正）；right=模型L（X负） | `control=(-Y,X,Z)`；不等于IMU安装矩阵，六面和手动俯仰待测 |
| USB逻辑供电 | 插USB前拔整个J12逻辑降压模块线束；J14保持连接 | USB经DevKit 5V/J14给编码器供电；USB与外部逻辑5V互斥；电池可独立供电机/头 |
| USB预算 | 禁Wi-Fi，逻辑含编码器预算<500mA | 实际USB/线缆/稳压器能力、电平和回流路径待测 |
| 回灌钳位 | R14=25.5kΩ0.1%、R15=10kΩ0.1%、R16=2.2MΩ1% | 估算开启8.73–9.04V；开启/迟滞/峰值/能量和热响应须示波器及负载验证 |
| 电压采样 | 30k/10k分压，ADC=VMAIN；软件过压8.65V | VMAIN可能与VM_MOTOR隔离；日志不代表所有回灌尖峰；两个节点分别测量 |
| 头/屏 | SER0037，初始±50°，未验证无PWM；GC9A01 SPI240台架后端 | 头中心/方向/线缆待测；最终有效Ø60屏仍未选定，保留无屏/模拟/分辨率解耦 |

J4/J5为**自定义XH6重压端子**，不是原厂六针排母的线序：

| 自定义针号 | 颜色提示 | J4控制左 / J5控制右 |
|---|---|---|
| 1 | 绿 | GND |
| 2 | 白 | B原始5V，先经LVC14 |
| 3 | 黄 | A原始5V，先经LVC14 |
| 4 | 蓝 | DEVKIT_5V |
| 5 | 黑 | M2 |
| 6 | 红 | M1 |

载板元件面pin1方焊盘，配合面镜像；必须依据针号与逐线通断，不能按颜色盲插。GPIO24项保持交接候选：ADC1/2/4，桥5–8，编码9–12，LCD13/14/15/39/40，IMU16，I2C17/18，ARM21，头41，心跳42，nFAULT47，ESTOP_OK48。保留USB19/20、UART43/44；不用启动0/3/45/46和N8R8的35/36/37。39–42与外部JTAG不可同时使用。

仍由硬件任务决定/补证：ANSMANN2447-0105长71mm与70mm预留冲突、成品电池保护/均衡/充电/回灌路径、真实传动和热余量；DevKit、IMU及显示的安装/光学冲突。软件没有修改机械定义、GPIO、符号、传感器量程或保护阈值。独立功率级资格须先签字，编译/模拟通过不能开启安全门。

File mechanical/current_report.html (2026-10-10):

# MORI V1.2-M1.55 当前构建报告

证据一致性：PASS。整机仍为 PROTOTYPE / UNVALIDATED，未制造放行。

- 源文件、当前检查和候选导出证据一致。

实际几何检查统计：{"PASS": 27, "FAIL": 0, "NOT_TESTED": 10, "BLOCKED": 12, "NOT_APPLICABLE": 0}。PASS 仅限原记录的检查范围；其余 BLOCKED / NOT_TESTED 仍保留。

- build
- validation
- delivery
- export

当前工程卡点 · 保留的图册快照 · 机器可读证据

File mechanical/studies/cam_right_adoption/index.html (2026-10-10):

# CAM USB 朝右已应用

V1.2-M1.54 · 只转动 CAM 整板与板载双麦。其余 198 件保持，原固定座和四枚螺钉继续使用。

右侧指机器人自身的 +X；正面对板看时，USB 出现在画面左边。

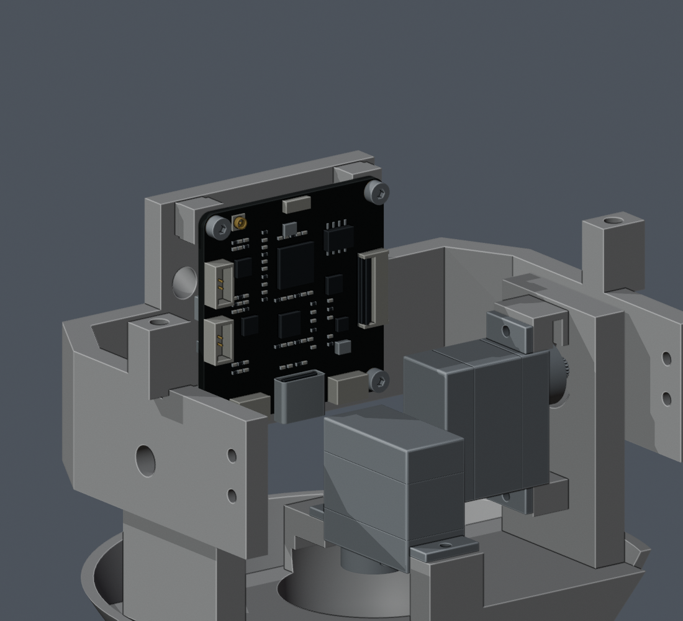
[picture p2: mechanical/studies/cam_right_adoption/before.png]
M1.53 USB 朝下的原模型


修改前 · USB 朝下

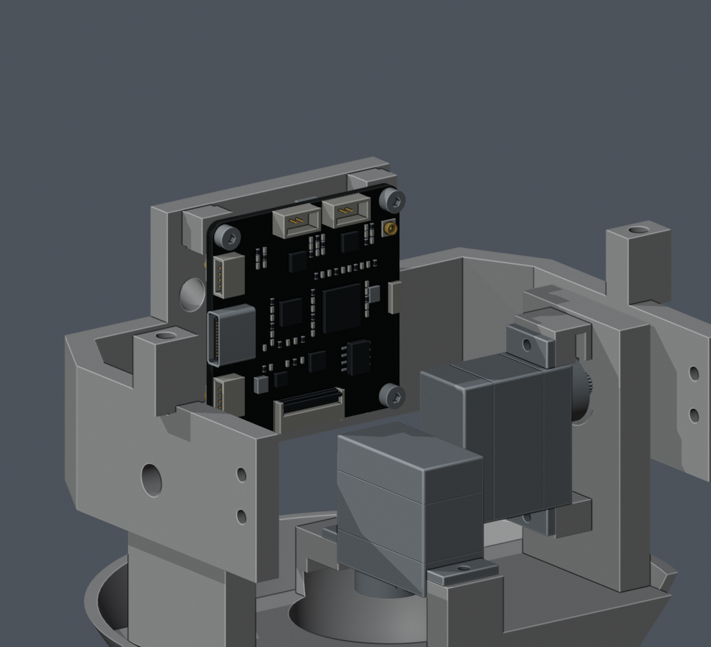
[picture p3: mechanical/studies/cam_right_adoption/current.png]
M1.54 USB 朝机器人右侧的实际主模型


修改后 · USB 朝机器人右侧

零位仰头 25°

接口 | 当前出口方向（头部零位）
CAM USB | 机器人右侧 +X
CAM 端相机 FPC | 机器人左侧 −X
CAM 端屏幕 FPC | 向下 −Z
麦克风源通道 L / R | 分别在下 / 上；名称保留源通道身份

## 安装路径

显示架与头壳后装。板卡向前错开 2 mm 下放 → 留高 8 mm，从右侧预接 USB → 下落并向后贴回固定座 → 锁四枚原螺钉。

130 个头部姿态、三种示例插头本体预留、12 条工具／螺钉路径及板卡装入路径复核通过。相机与屏幕本体位置不变。

完整线束仍需重排和验证。三种 USB 本体只是空间预留，未包含最终插头的金属鼻端、插合及软线。麦克风／RF、PA12 和实物配合尚未验证；没有制造放行。

当前 Blender 主模型 · 更新后的装配视频 · 检查范围与记录 · 当前图册

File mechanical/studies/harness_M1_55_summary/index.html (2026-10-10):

# M1.55 线束研究与待补资料

2026-10-10。主模型 M1.55、装配动画 M1.55-A1；以下线束研究未采用。硬件合同保持 P5R7。

完整线束：BLOCKED。七条已知参考的名义运行检查已完成，实际材料、接口、裁线和完整带线装配仍未完成。局部 PASS 不等于实物或制造资格。

机械图册 · 当前状态 · 待补资料 · 已采用模型更新

## 已完成的具体参考范围

- 12 条身体／颈部容量前段的名义偏航运动、弯折、公共数值长度、实体间隙、66 组互线和自身接近检查。
- 7 条已知上段：4 根 CAM 信号、2 根电源与 1 根 CC；名义偏航 −60°～+60°、俯仰 −20°～+25°范围的长度、弯折、实体、21 组互线及自身检查。
- 前段与已知上段 84 组比较，包括 7 组同线接续及 77 组其他前段互线；保持原 0.3 mm 规划间隙目标。

使用的是名义几何与分段线径分配。它们不定义真实粗细线接续、实际压接、夹持或可下发的裁线尺寸。三条头舵机和两条喇叭参考尚缺完整上段，不能据此称整束通过。

## 装配研究的限制与未通过方式

研究方式 | 实际结果 | 不能据此推出
裸 PH 端子容量路径 | 两种容量框、6,090 个连续区间通过；未采用真实压接／保护／附线。 | 真实带线逐根装入、操作空间或完整装配通过。
身体前段预铺后装驱动座 | 12 条参考均在已检装入路径与 Pitch_Yoke 相交，未采用。 | 所有临时软线整理方法都不可能。
整束随头部搬入 | 19 个已知参考段检查；10 条身体前段与 Yaw_Base 相交，未采用。 | 缺失的五条上段已被覆盖，或数学切点等于实际自由端。
PHR-4 外形容量与带线插合 | 外形容量框通过；五种固定头端提线候选均有 Yaw_Base 净距失败，20 处独立复现。 | 容量框定义了内腔、实际插深、压接或握持。
先端接身体、再装承重桥 | 原路径及直落候选各 19 处失败；38 处独立复现为 36 容量管相交、2 规划净距不足，未采用。 | 其他有真实自由端的分步穿线／临时整理方法已被排除。

未采用插合提线候选的实际剖面

图为有限候选姿态下的容量管与原生实体剖面。容量线径没有成为最终线材选型，图示不是实物相撞的测量记录。

## 剩余四组完整工作

1. 补齐五条缺真实端点的上段及完整路线。
2. 确定实际材料、粗细线接续、工艺余量与供应商裁线。
3. 确定配对接头、压接、保护、第一可弯点、夹持与应力释放。
4. 完成实际带线穿入、插合、临时整理、拆壳／闭壳，再同步正式模型和动画。

喇叭壳体出口至现有插头末端 150 mm 已由用户报告，含插头。插头尺寸待补充；舵机附件和微雪排线按用户决定到货后核对；CAM 供电源端仍待正式硬件交接。询问稿没有发送。

## 记录包与复核边界

下载研究记录包 · 成员哈希与未包含项

包内有数值记录、脚本、日志和原页面快照；保留原日期和失败结果。二进制缓存、比较 Blender、图片和第三方原始载荷仍在本地，本包不是完整可执行备份。页面快照中的历史链接也不代表当前公开入口。恢复后读取记录，不应跳过缺失输入而声明重现 PASS。

PRINTABLE／PURCHASED_REFERENCE／PLACEHOLDER 及证据等级沿用各源记录。原型未完成实物装配、材料强度、线束寿命或制造验证；manufacturing_release=false。

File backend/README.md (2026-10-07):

# MORI Gateway

本地 `.venv/bin/python -m backend.run`，只监听127.0.0.1:8765。模拟设备同协议运行。
生产从同域HTTPS加载控制台，默认使用该域API；手机填写经过认证的HTTPS域。HTTP只容许本机回环开发。
WebSocket第一条消息携带独立可撤销凭证，后续每消息验权；查询串不放token。Origin允许列表独立配置。
配对碼在服务端600秒内单次有效，5次错误后需重启重新生成。当前CLI/code流程仅为开发绑定；实机物理按钮配网仍未绑定硬件。

设备命令在 `/ws` 或 `/api/command` 走 MORI/2。`/xiaozhi/v1` 是独立小智v1 Opus适配，使用Authorization header，
支持hello/listen/abort、16kHz单声道60ms输入和24kHz输出；拒绝MCP/未知工具。Token须有interaction权限。
MORI动作仍走本机租约；不会因语音/图像文字给予任意运动授权。

## 腾讯云配置与部署

当前未提供服务器访问资料，**没有登录、部署或改防火墙**。先在用户已授权的服务器手动运行 `tools/probe-server.sh`。
起步评估配置为2核、2GB RAM、10GB可用盘，仅是轻量适配/SQLite估算，不是承载多人/视频的性能承诺，不要求GPU。

1. 构建网页 `pnpm build`；复制 `.env.example` 为 `.env`，权限600，设置真实域名与Origin。
2. 默认MORI_PROVIDER=mock。明确启用腾讯云时填服务端SecretId/Key、地域、模型、音色、月调用上限。
   空预算禁止真实服务调用；没有自动充值。预算已持久化，重启不会重置当月计数；失败调用也先占额度，价格未知记NULL，须对账实际账单。
3. 服务器已确认资源/域名/端口后才运行 `docker compose -f backend/compose.yaml up --build -d`。
   容器镜像tag+digest锁定，Caddy提供HTTPS/WSS，gateway只在Compose内部暴露端口。
4. `/health`检查、持久卷mori-data、独立撤销凭证、Caddy证书卷均有配置。Compose本机未运行（无Docker），部署仍NOT_TESTED。

ASR / Hunyuan LLM / TTS各自SDK适配；按需VLM单独HTTPS接口，不能把某一网页会员当API。
默认自然普通话、简洁友好，音色可配置，不模仿具体真人。所有服务异常应呈现REJECTED/错误，不回退成虚假的真实支持。
目前半双工，设备级AEC、离线唤醒漏检/误触发、真实打断、嘈杂环境与时延待测；Mock不计入云成功率。

## 记忆与恢复

SQLite迁移v1 + FTS5 + 中文字面检索，用户/设备双重作用域。类别含事实、偏好、摘要、推断；推断不能自动升级为事实。
必须明确确认、来源ID非空；纠正保留冲突记录；关闭后不读取/新增，仍可删除/导出。
删除重建索引、清正文/冲突/结果缓存，VACUUM，并追加独立删除清单。数据库正文没有独立摘要缓存可残留。
原始录音/视频不写磁盘；用户上传或前端导出文件由用户管理。

```sh
.venv/bin/python -m backend.backup backup --data .state --backups .state/backups
.venv/bin/python -m backend.backup prune --backups .state/backups
# 先停止gateway，删除清单必须独立保留，再恢复指定快照：
.venv/bin/python -m backend.backup restore --data .state --snapshot .state/backups/具体快照.sqlite --gateway-stopped
```

备份保留7天，`prune`由管理员安排执行；本任务没有创建定时任务或远程自动化。恢复必须重放当前删除清单，
不能用旧快照复活已经删除的事实。凭证库不从旧备份恢复，避免复活撤销凭证。恢复/重启/隔离/冲突/删除有实际测试。

日志含命令ID、设备单调时钟、结果码与性能，不输出服务密钥或原始音视频。当前个人原型不包含账户社交、支付或自动回充。

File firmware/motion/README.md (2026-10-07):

# MORI独立软件工作副本 SW-0.4

初始来源为HW-SW-0.3快照，本次按用户指令选择性合并HW-SW-0.4。已保留软件状态机、协议、模拟HAL、安装矩阵和实时性修复；本目录没有被上游最小固件覆盖。

从MORI根目录执行：

```sh
bash software/scripts/idf_build.sh
bash software/scripts/test_host.sh
python3 -m unittest discover -s software/tests -p 'test_*.py' -v
python3 software/scripts/verify_delivery.py --require-current-handoff
```

仅构建和离线验证，不连接/烧录设备。ESP-IDF v5.5.2及dependencies.lock保持。功率、平衡、头部、轴四安全门默认n，增益全0；任何实物功能NOT_TESTED。

轮比例唯一运行时来源为components/mori_core/include/mori_io.h：#4863，48CPR已含x4，精确20.4086667:1，1:1候选皮带，979.616 counts/rev。头部/显示/电池阈值不变。接线、电平、J12/J14 USB互斥供电、VMAIN/VM_MOTOR边界和全部实测前置条件见../../README.md、../../docs/debug_manual.md、../../docs/hw_sw_0_4.md。

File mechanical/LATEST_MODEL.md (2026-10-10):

# 最新主模型

当前：**V1.2-M1.55**，保存后的总装文件为 [mori_v1_2.blend](mori_v1_2.blend)。
请从本文件所在的当前工作树打开它；Documents/MORI 中的历史副本不代表此次同步。

[R2采用与检查](../docs/M1_55_MODEL_UPDATE.md) · [装配动画 M1.55-A1](animation/index.html)

模型已采用 C6 通道、CAM USB 朝右及颈部装入 R2。
完整研究线束未采用，实际舵盘和柔性排线按用户决定到货后核对。
原生模型、打印件和动画来自同一保存源；数字 PASS 不代表实物或制造放行。

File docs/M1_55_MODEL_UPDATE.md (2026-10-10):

# M1.55 模型与到货前资料

当前主模型、电子细模、STL、图册和装配动画已同步用户批准的 R2 颈部装入修正。Pitch_Yoke 扩大内部孔道并开放后侧颈壁，保留轴承配合外圆、舵机座和运动范围。相对 M1.54，其余 200 件原生零件和全部硬件位姿保持，不增加打印件或紧固件。此前 C6 通道加宽和 CAM USB 朝机器人右侧的改动继续保留。

[最新模型入口](../mechanical/LATEST_MODEL.md) · [图册](../mechanical/index.html) · [装配视频](../mechanical/animation/index.html) · [当前状态](CURRENT_STATUS.md)

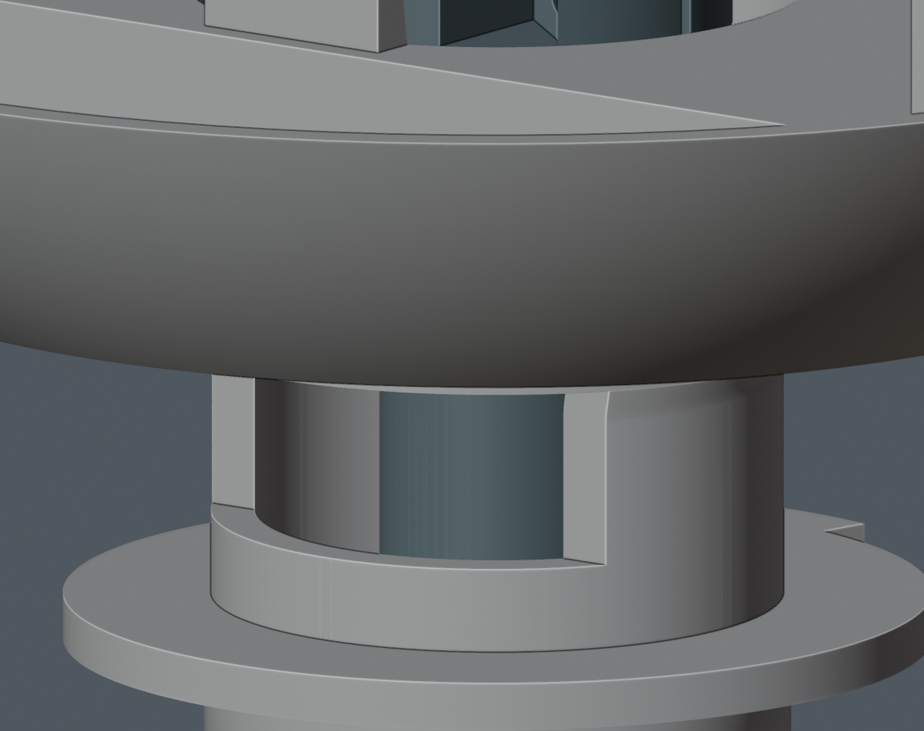
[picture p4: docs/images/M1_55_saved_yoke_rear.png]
R2 保存后的颈部结构


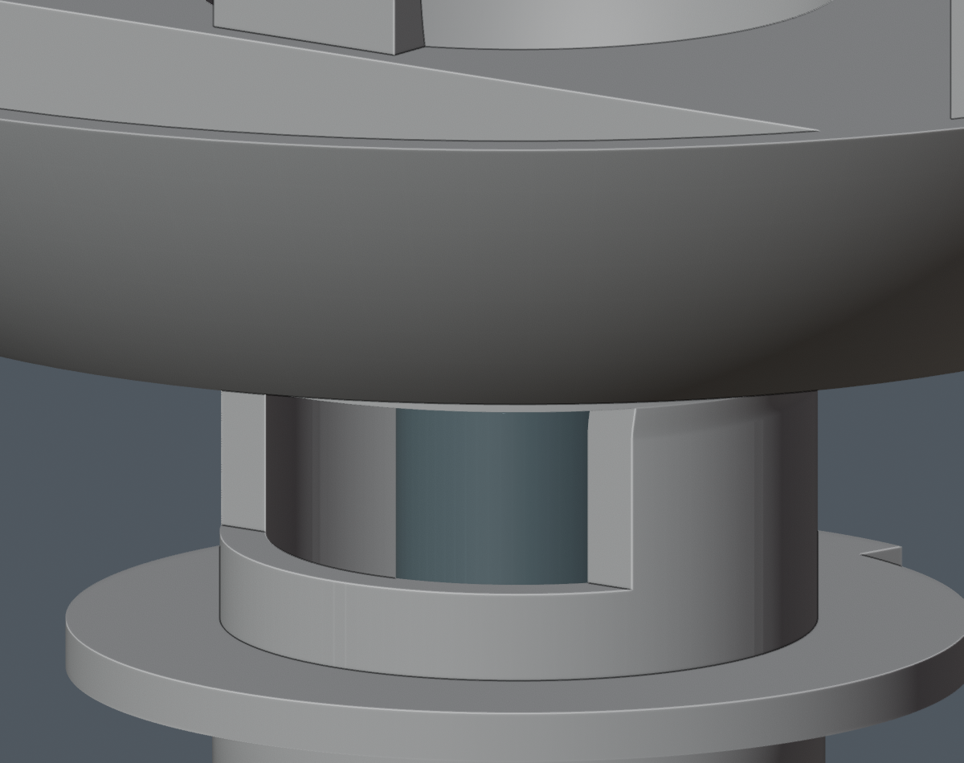
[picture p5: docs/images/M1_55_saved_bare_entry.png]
裸反力夹装入示意


第二张图中的反力夹位移仅用于展示装入，主模型安装位置不变。
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

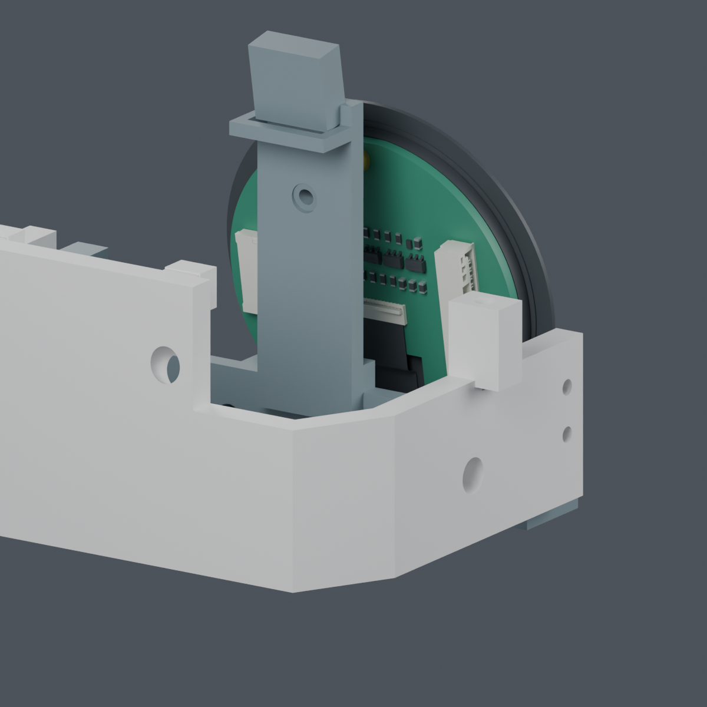
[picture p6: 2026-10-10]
mechanical/renders/screen_outline_review.png

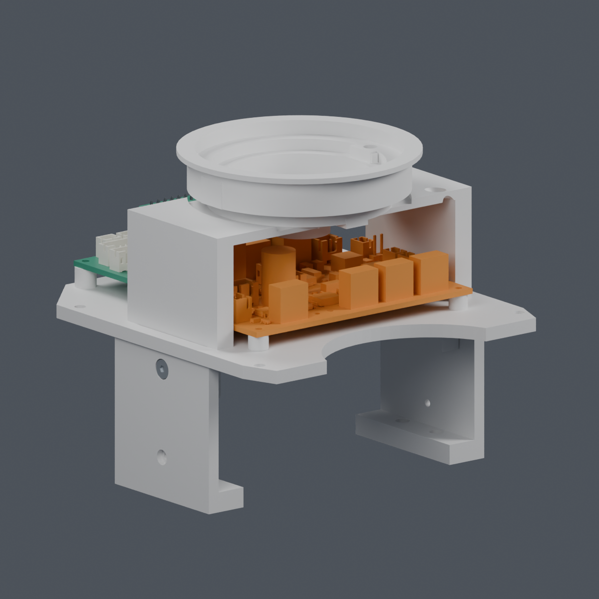
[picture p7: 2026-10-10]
mechanical/renders/flush_bridge.png

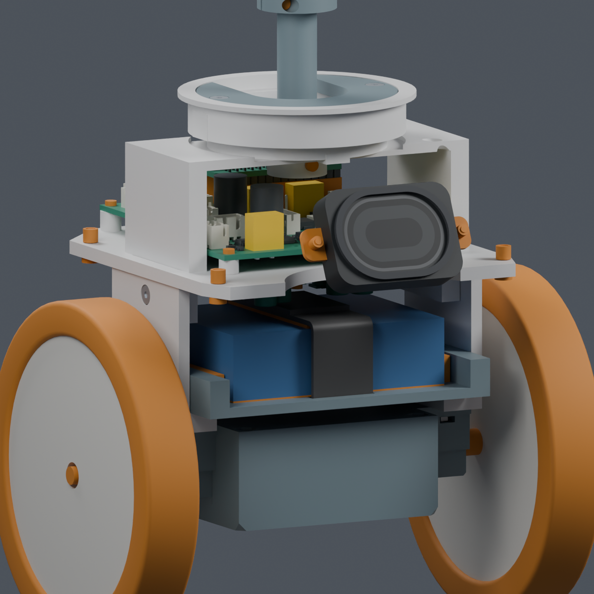
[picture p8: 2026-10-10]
mechanical/renders/belly_detail.png

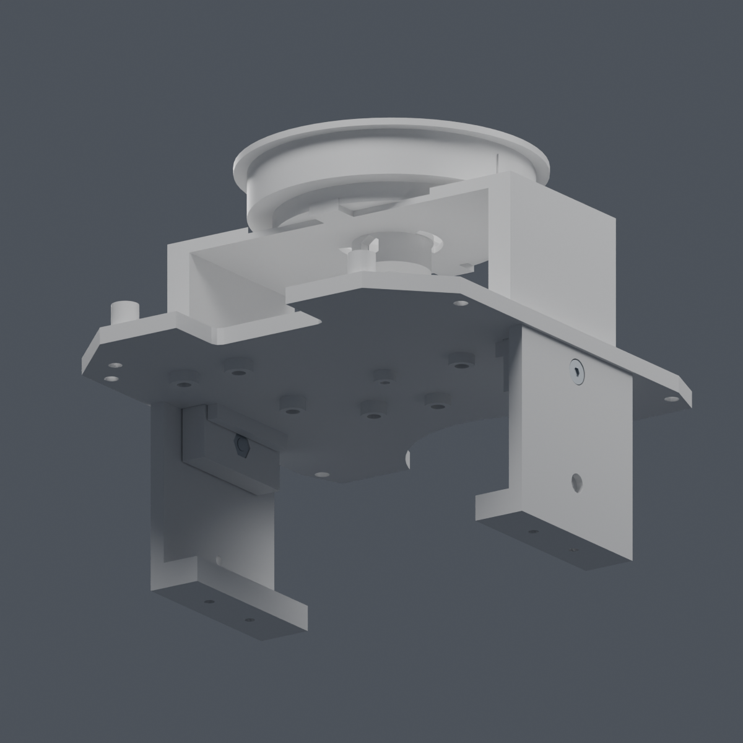
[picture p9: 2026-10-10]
mechanical/renders/flush_bridge_underside.png

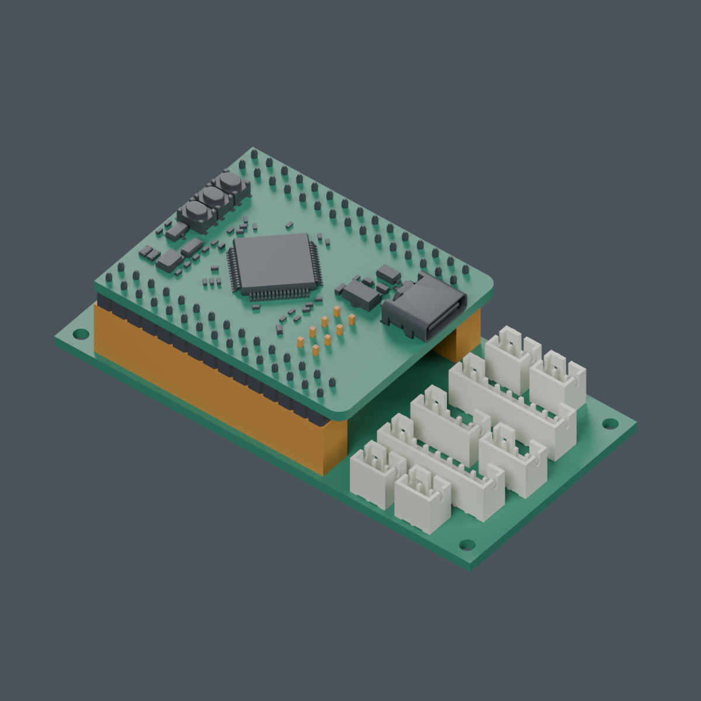
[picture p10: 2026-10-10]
mechanical/renders/pcb_motion.png

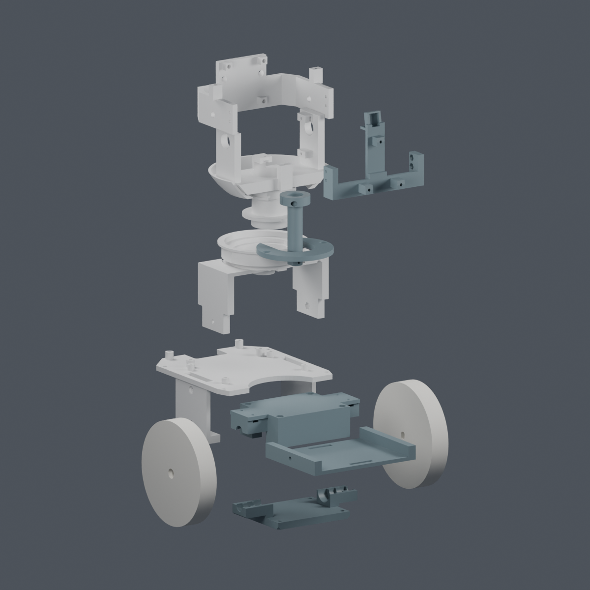
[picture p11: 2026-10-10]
mechanical/renders/structure_exploded.png

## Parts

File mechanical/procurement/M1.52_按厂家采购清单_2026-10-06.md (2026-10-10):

# MORI 按厂家采购清单

整理日期：2026-10-06；采购进度更新：2026-10-08。数量按 **1 台样机，不含备件**。用户已确认微雪 CAM33700、LCD35079、头部 SCS0009、轮驱 S288、两类舵机调试板及 WeAct F412 已下单，均待收货；头部舵机完整商品型号已确认为 **SC-0090-C001**。链接、已知价格和订单明细缺项见 [采购记录](采购记录.md)。

依据当前机械模型 **V1.2-M1.52**、硬件交接 **V1.2-H0.5-P5R7** 和用户后续选型。以下先用于购买样件、实测和询价；整机制造放行仍未完成。微雪两项已记录购物车价格，其他价格、国内库存、税费和运费尚未核定，不能确认整机总价满足 1000 元预算。

## 1. 成品模块：按这 5 家联系

| 厂家／渠道 | 产品 | 单机数量 | 采购进度与型号／附件核对 |
|---|---|---:|---|
| **飞特 FEETECH**，原厂或经原厂确认的供货商 | **SC-0090-C001／SCS0009 串行总线舵机，单轴版本** | **2 个** | **已下单、待收货；2026-10-08 用户确认完整商品型号。** 头部偏航、俯仰各 1 个。到货核对具体修订、花键、配套舵盘、中心锁紧螺钉及原装线；配件是否随货尚未确认。 |
| **微雪 Waveshare**，官方商城／官方店 | **ESP32-S3-CAM-OV3660，SKU 33700** | **1 套** | **2026-10-07 用户确认已下单，截图价 ¥109.08**，收货待确认。已选 OV3660 相机版本；到货保留原装相机排线。详见 [采购记录](采购记录.md)。 |
| **微雪 Waveshare**，同一单购买 | **1.85inch Touch LCD Module，SKU 35079** | **1 套** | **2026-10-07 用户确认已下单，截图价 ¥99.99**，收货待确认。仍为 1.85 英寸圆屏、360×360；到货核对附带的 18P FFC 与 15P 连接线。详见 [采购记录](采购记录.md)。 |
| **宇树 Unitree**，官方商城／销售渠道 | **YS-342026-S288 无刷数字舵机** | **2 个** | **2026-10-07 用户确认已下单、待收货。** 左右轮各 1 个，所选为 S288 塑料版本。到货核对两套原装 PH2.0 线及输出端配套螺钉；USB 调试模块另列为台架工具。 |
| **WeAct Studio**，官方淘宝店 | **STM32F4 64Pin CoreBoard V1.1，STM32F412RET6 版本** | **1 块** | **2026-10-07 用户确认已下单、待收货。** 到货核对 64Pin、V1.1、F412RET6 及排针是否已焊；当前装配要求元件朝上、排针朝下，E 接口还需实物核对。 |
| **用户提供规格书的原卖家／深圳市昊林电声科技有限公司** | **SP3040：规格书标注 YH-SP3040-08／WSS-SP3040-08，4Ω 3W 带腔喇叭** | **1 个** | 按原规格书确认同款：箱体 42×30×9 mm，含耳总长 56 mm，孔距 49±0.5 mm。两种前缀均出现在所供资料中，请卖家对图确认，不能只按“3040”购买。当前可下单链接尚未核实。 |

**优先拿到飞特两只舵机的完整配件和微雪 CAM 套装。** 它们直接影响尚未闭合的舵盘连接、相机排线和插头实测。屏幕与 WeAct 同批到货也有助于核对排线、排针和插座装配。

当前 WeAct 型号按已接收硬件合同为 **F412RET6**，用户于 2026-10-07 比较 F413 路线后确认保留；早期资料的 F413 和常见 F411CEU6 BlackPill 不作为本次下单型号。确认记录见 [采购记录](采购记录.md)。

### 台架调试工具

| 工具 | 配置数量 | 当前进度 |
|---|---:|---|
| 头部舵机 USB 调试板，前述推荐 FE-URT-1 的 SCS TTL 接口 | 1 块，两只头部舵机共用 | 用户已确认购买、待收货；具体型号、订单数量及价格未提供 |
| 轮驱 USB 调试板，前述推荐宇树 S288／J288 单总线串口转 USB 模块 | 1 块，两只轮驱共用 | 用户已确认购买、待收货；具体型号、订单数量及价格未提供 |
| WeAct 烧录／调试工具：板载 USB DFU 优先，公司 J-Link 备用 | 无新增调试器采购；需要时借用 J-Link | 2026-10-07 用户确认可使用公司的 J-Link，暂不采购 ST-Link；具体型号与连接线待使用时核对 |

调试板作为外部工具记录，不加入整机内部模型。两类总线的适配要求不同，不能据此视为可互换；厂家入口见 [飞特 URT-1 接口说明](https://www.feetechrc.com/wp-content/6-how-does-single-chip-microcomputer-control-serial-port-steering-gear.html)及 [宇树购买页的 Single-Bus Serial-to-USB Module 选项](https://shop.unitree.com/products/brushless-digital-servo)。

WeAct 的 USB DFU 与 SWD 下载途径参考 [官方教程](https://www.weact-tc.cn/2019/11/30/STM32Download/)；借用 J-Link 是用户确认的工具安排，尚未实机验证，不计为新增采购或已验证的调试连接。

## 2. 官方入口与附带配件

- **飞特**：[官方产品页](https://www.feetechrc.com/6v-23kg-serial-bus-steering-gear_65522.html)、[SCS0009 原厂规格书](https://www.feetechrc.com/Data/feetechrc/upload/file/20220915/6379883463905538176347522.pdf)。官网同页有 SCS0009／SCS009 及 20T／25T 混杂信息，项目参考的是 SCS0009 旧版 20T 接口，必须让卖家匹配实发版本和舵盘。项目中的 [JuxiTech JX00099 渠道](https://www.juxitech.com/zh-hant/collections/actuation/products/feetech-scs0009-serial-bus-servo)仅是既有线索，本轮未核实其库存和版本。完整厂家问题见 [FEETECH.txt](https://github.com/deanxizian/MORI/blob/48fe22aa75554c9d7bb237e2d2dcacca7f83dde1/mechanical/studies/prearrival_finish/supplier_questions_M1_50/FEETECH.txt)。
- **微雪 CAM**：[官方型号与 SKU 对照](https://docs.waveshare.com/ESP32-S3-CAM-OVxxxx)、[官方系列购买页](https://www.waveshare.com/product/arduino/boards-kits/esp32-s3-cam-ov5640.htm)。购买页 URL 含 OV5640，但有多种相机选项，需选 **With OV3660 camera／33700**。官方套装表包含相机和一只 1217、8Ω／2W 小喇叭；后者可以留作测试，整机仍使用用户选定的 SP3040。
- **微雪屏幕**：[官方购买页](https://www.waveshare.com/product/1.85inch-touch-lcd-module.htm)。官方套装表包含 GH1.25 15PIN 线和 **18PIN、0.5 mm 间距、200 mm、同面触点 FFC**；下单核对随货内容，不重复购买同一条附带线。200 mm 是套装长度，并不代表最终走线长度已经验证。
- **宇树**：[官方购买页](https://shop.unitree.com/products/brushless-digital-servo)、[官方产品资料](https://www.unitree.com/DigitalServo/)。手册每套列有舵机与 PH2.0 线；输出连接螺钉的随货情况仍需确认。页面同时有一般发货提示和 S288 缺货预订文案，实际交期应向销售确认。
- **WeAct**：[官方淘宝店](https://weactstudio.taobao.com/)、[官方产品资料与店铺入口](https://github.com/WeActStudio/WeActStudio.STM32F4_64Pin_CoreBoard)。64Pin 系列有多个 MCU 版本，必须按表中完整型号选择。
- **SP3040**：[用户提供的原规格书](https://github.com/deanxizian/MORI/blob/48fe22aa75554c9d7bb237e2d2dcacca7f83dde1/mechanical/sources/SP3040/SP3040_user_specification.pdf)。厂家名称来自该资料；未核实原卖家的现售链接，不借用其他同外观喇叭的安装尺寸。

## 3. 轴承、紧固件与加工件

| 厂家／渠道 | 产品或服务 | 单机用量／范围 | 当前处理方式 |
|---|---|---|---|
| **NSK／正规轴承经销商** | **6806ZZ，30×42×7 mm**，头部偏航轴承 | **1 个** | 当前模型采用的轴承尺寸。旧 6804ZZ、20×32×7 已被替换。按 [NSK 目录](https://www.oss.nsk.com/tw/products/bearings/ball-bearings/deep-groove-ball-bearings/single-row-deep-groove-ball-bearings/6806zz-apn.html)询价；PA12 配合仍需试装。 |
| 微型轴承厂家／经销商，品牌待定 | **686ZZ，6×13×5 mm**，轮轴支承轴承 | **4 个** | 每轮 2 个。尺寸已有 [厂家目录参考](https://www.smbbearings.com/firebrick/ckeditor/plugins/upload/Uploads/Documents/bearingpdfs/686ZZ-miniature-bearing-6x13x5mm.pdf)，具体采购品牌／后缀未冻结。 |
| 微型轴承厂家／经销商，型号待定 | 俯仰支承轴承，当前几何 **5×12×4 mm** | **2 个** | 先核对具体厂家型号、密封形式及公差，不能仅凭几何占位下单。 |
| 标准紧固件供应商；FINE 为嵌件参考来源 | M2／M3 螺钉、金属螺母；SL-M2×3／SL-M3×4 嵌件参考系列 | 按当前紧固件表汇总 | 不按旧清单数量购买。当前头部耳座已改穿栓螺母、身体拼缝已取消部分紧固件；舵盘相关最终螺钉仍待配件确定。嵌件型号、PA12 孔配合和数量需随最终接口表核定。 |
| **嘉立创 3D 打印** | 全部机器人打印件，**PA12 尼龙** | 当前机器人 **16 件** | 先做必要配合试件，再提交最终结构件。当前导出目录有 21 个 STL，不能直接视为 21 件整机零件全部下单。[官方 PA12 服务资料](https://www.jlc-3dp.cn/technicalColumnsDetails/59512.html)。 |
| CNC 机加工供应商，尚未指定 | 轮驱金属法兰／短轴组件 | 左右共 **2 套** | 属于项目定制件，按最终加工图报价；不是宇树随货轴，也不以打印 STL 代替金属加工图。头部传动短轴、轴向锁紧另待舵盘接口确定。 |
| 线束加工供应商，尚未指定 | 按图制作的整机线束 | **1 套** | 制作方式已经确定为供应商按图加工；尚需完成接插件配对、长度、分支及走线路径，不把规划线径或占位插头当作最终订货规格。 |

## 4. 自制电路板与立创采购

四块自制 PCB 的制造／贴片可交 **嘉立创**，离散元件按硬件任务的最终 BOM 从 **立创商城**配齐。本表不重复展开每个电阻、电容和连接器。

| 自制板 | 已接收版本 | 单机数量 |
|---|---|---:|
| 运动基板／载板 | MORI_motion_P5R7 | 1 |
| IMU 板 | MORI_imu_P5R4，保持 20×16 mm、两孔 | 1 |
| 电源板 | MORI_power_P5R6 | 1 |
| 后置接口板 | MORI_rear_P5R7 | 1 |

这些是当前交接版本，**本表不代表 PCB 已获制造放行**。板内 TI 电源器件、TDK ICM-42688-P、连接器等随硬件 BOM 配套，避免整板和单独模块双重采购。

## 5. 还不能给出确定厂家下单的项目

| 项目 | 当前状态 | 下单前缺少什么 |
|---|---|---|
| 成品 3S 电池 | 机械保留 **71×55×20 mm 小型成品包候选**，没有改成六节 18650 | 最终厂家／型号，以及实际尺寸、放电能力、保护、温度采样和引线接口；现有包络不是已确认电池采购型号。 |
| 两只轮胎 | 当前轮胎几何 Ø105×18 mm；现货轮胎尚未选定 | 实际商品型号、轮毂配合及必要的尺寸调整。 |
| 3S 充电模块及适配器 | 尚未选定 | 电气方案、额定、连接方式、尺寸和价格；后置 Type-C 接口板本身不等于完整充电器。 |
| 电机／舵机供电支路、保险及制动耗能器件 | Pololu D36V50F9 #4094／D24V22F6 #2859 仍为工程参考，未形成最终采购项 | 硬件确认工作点、热设计、价格和安装接口。它们与已集成的两路 5V 降压电路不是同一项。 |
| WeAct 对插排针／排母 | 有目录候选，E 接口实际配合未闭合 | 实发板排针、成品孔和完整插接叠层；先拿开发板样件，避免整套插座提前买错。 |
| 头部舵盘、反力连接及锁紧件 | 取决于 SCS0009 实发套装 | 厂家完整配件图或实物测量，随后完成最终接口和加工规格。 |

## 6. 从旧采购表中排除的重复项

- 不额外买两块 5V 降压模块：目前是电源 PCB 上的两路 TPS54302 电路。
- 不额外买 OV3660 相机、独立麦克风、音频编解码板或功放板：所选 CAM 套装／板载器件已有对应功能。
- 不额外买通用轮驱 FOC 板：S288 自带驱动。
- 不按旧型号买大喇叭、4 英寸屏、旧偏航轴承或六节 18650 电池组。
- 不按旧外壳方案买独立 function／reset 按钮或额外屏幕、相机透明保护片。

## 依据与可追溯记录

2026-10-06 整理时新增本清单；2026-10-07 按用户确认补充微雪两项下单进度，并新增采购记录及原始价格截图；同日记录保留 WeAct F412 的决定，以及随后头部舵机、轮驱、两类调试板与 WeAct 的下单／待收货确认。2026-10-08 用户补充头部舵机完整商品型号 SC-0090-C001，并重新核对飞特官方页面的 SCS0009 对应关系；未将型号确认解释为附件或花键已验证。后五项未提供完整订单明细和成交价。未修改模型、硬件合同或硬件源文件。查询方式：读取项目 JSON 和当前交付记录，核对厂家产品页／套装清单、用户提供的喇叭规格书、购物车截图和本次文字确认。

| 来源 | SHA-256 |
|---|---|
| [当前几何配置](../../config/geometry.json) | `5fbe7d99aeebf2c60dad22a182084868e9495ea4b55a58c022e3b26fe114043b` |
| [硬件型号合同](../../contracts/components.json) | `376246dbf550094b26406854b8246fbe68e3d8ffb6a0ca6e21ffbe81ba31849d` |
| [M1.52 当前交付记录](https://github.com/deanxizian/MORI/blob/48fe22aa75554c9d7bb237e2d2dcacca7f83dde1/mechanical/studies/prearrival_finish/reaction_access_M1_51/delivery.json) | `18187789c09cf982d1c43e36d3a2792b1f87e5b95a35264f53da8baa9dbfb0f1` |
| [SP3040 用户规格书](https://github.com/deanxizian/MORI/blob/48fe22aa75554c9d7bb237e2d2dcacca7f83dde1/mechanical/sources/SP3040/SP3040_user_specification.pdf) | `f16071502c87b41df65d2a6e4f258b4ebaf96ef2c4b7f22cec23dad565fbce43` |

已核对厂家公开资料不等于现货、实物测量或完整装配验证；采购页中没有对应选项时，向卖家提供完整型号及原图核对。

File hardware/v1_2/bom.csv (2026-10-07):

revision | id | category | purpose | quantity | quantity_unit | full_model | board_revision | specification | interface | source_ids | source_date | data_status | dimensions_mm | mass_g | mass_tolerance_g | shaft_hole_interface | connector_clearance_mm | mechanical_contract_keys | mounting_release | purchase_channel | purchase_option | unit_price_cny | currency | quote_date | stock_status | stock_quantity | tax_basis | shipping_basis | confirmation_status | selection_status | included_in | alternative_model | readaptation_requirement | missing | notes | ratings | subtotal_cny | price_status | exact_variant_match | procurement_evidence | schematic_references | included_components | source_urls | source_local_paths | package_evidence_status | package_read_date | package_source_sha256
V1.2-H0.5-P5R6 | wheel_servo | actuator | 左右轮执行器 | 2 | piece | Unitree YS-342026-S288 |  | 6.4–12.6 V；12 V空载16.5 rad/s；0.6 N·m为反向工况最大/堵转值 | 6 Mbps 8N1半双工TTL；集成驱动/双编码器 | ["HW12-U1", "HW12-U2", "HW12-U3"] | 2026-09-22 | VENDOR_DOCUMENTED | {"vendor_axes": "W,H,D", "overall_whd": [20, 34, 26], "includes_plug_and_cable": false} | 19.5 |  | 按原厂手册和结构独立承载轮轴方案校核；最终孔位未冻结 |  | ["wheel_servo"] | False |  | S288，不买J288；连接件与线材包含情况待核 |  | CNY |  | UNKNOWN |  | UNKNOWN | UNKNOWN；国内运费另列，不假设包邮 | BLOCKED | PRIMARY_SPECIFIED_NOT_RELEASED |  |  | 更换须重核供电、协议、包络、重量与成本；未授权自行改主路线 | ["国内精确规格价格/库存/税运", "连续扭矩-速度/温升曲线", "TTL阈值/方向释放/掉电状态", "固件版本与协议差异", "输出径向轴向承载与回差", "接插件净空"] | 内驱不另购FOC板；反馈扭矩不证明有输出力矩传感器；最大扭矩不能设为无限时限幅。 | {"max_opposed_direction_stall_torque_Nm": 0.6, "continuous_torque_Nm": null, "no_load_speed_rad_s_at_12V": 16.5, "no_load_current_A_at_12V": 0.27, "standby_current_A_at_12V": 0.05, "nominal_gear_ratio": 288.35, "rotor_encoder_bits": 15, "output_angle_states": 8192, "quadrature_AB_multiplier": null} |  | UNCONFIRMED
V1.2-H0.5-P5R6 | head_servo | actuator | yaw/pitch头部执行器 | 2 | piece | FEETECH SCS0009 | 参考2020-11-23 A/0；采购修订未确认 | 6 V支路目标；并发峰值电流待核 | 独立半双工TTL 8N1；文档默认1 Mbps | ["HW12-F1", "HW12-SPEC", "HW12-P2"] | 2026-09-22 | VENDOR_DOCUMENTED | {"body_nominal": [23.2, 12.1, 25.25], "body_drawing": [23.3, 12.1, 25.25], "ear_span": 32.5, "ear_hole_pitch": 28.5, "ear_hole_diameter": 2, "output_total_depth": 28.45, "includes_plug_and_cable": false} | 13.2 | 1 | 20T/OD3.95；输出螺钉M2.0×4；5264-3P线15cm；1GND/2VCC/3TTL，观察方向待确认 |  | ["yaw_servo", "pitch_servo"] | False | https://www.juxitech.com/zh-hant/collections/actuation/products/feetech-scs0009-serial-bus-servo | JuxiTech JX00099，网页型号FEETECH SCS0009；机械/电位器版本待核 | 103 | CNY | 2026-09-22 | PUBLISHED_IN_STOCK |  | UNKNOWN | UNKNOWN；国内运费另列，不假设包邮 | BLOCKED_VARIANT_TAX_AND_SHIPPING | PRIMARY_SPECIFIED_NOT_RELEASED |  |  | 更换须重核供电、协议、包络、重量与成本；未授权自行改主路线 | ["采购修订匹配/税运；国内103元型号报价已有", "保持电流/噪声/温升及原始A0连续额定的适用版本", "TTL阈值/寄存器与零点实测"] | 文档位置300°/1024；位置/速度/负载/电压/温度回读尚未实测。名义23.2与图23.3冲突，不能冻结安装孔。 国内商家中国CNY页面显示103元/个、有货、深圳发货；网页编码器说明与旧原厂规格冲突，暂不据此采购。 | {"at6V": {"rated_torque_Nm": 0.073549875, "rated_current_A": 0.4, "stall_torque_Nm": 0.22555294999999997, "stall_current_A": 1.0, "no_load_current_A": 0.15}, "at4p8V": {"rated_torque_Nm": 0.063743225, "rated_current_A": 0.3, "stall_current_A": 0.8}, "position_feedback": "carbon potentiometer in2020A/0;300deg/1024, current sold revision not matched", "backlash_deg_documented_max": 0.5} | 206 | PRIOR_RECORDED_QUOTE_RECHECK_REQUIRED | False | hardware/v1_2/procurement/SCS0009_JX00099_price_observation.json
V1.2-H0.5-P5R6 | motion_mcu | controller | 身体运动与本机保护 | 1 | piece | WeAct STM32F4 64Pin CoreBoard V1.1 / STM32F412RET6 | V1.1 2026-05-30; populated F412RET6 option | 5V board input; local3.3V; 512KB flash /256KB SRAM; HSE8MHz -> SYSCLK96MHz proposed | USART1/2/6 + SPI1/EXTI0 + ADC1 + top SWD | ["HW12-WEACT", "HW12-F412-RM", "HW12-F412-DS"] | 2026-09-22 | VENDOR_DOCUMENTED | {"board_xy": [41.6, 33.22], "populated_height": null, "includes_cable": false} |  |  |  |  | ["motion_mcu"] | False | https://weactstudio.taobao.com/ | 64Pin V1.1 STM32F412RET6; not F411CEU6 BlackPill |  | CNY |  | UNKNOWN |  | UNKNOWN | UNKNOWN；国内运费另列，不假设包邮 | BLOCKED | EXPLICIT_ADAPTATION_PROTOTYPE |  |  | 更换须重核供电、协议、包络、重量与成本；未授权自行改主路线 | ["国内所选规格报价与板修订", "完整堆叠高度/质量/插拔空间", "实物时钟与6Mbps物理链路"] | ADR-HW-V1_2-002.md; pinout/DMA frozen for prototype; no motor or application-count change. |  |  | UNCONFIRMED |  |  | ["MORI_motion_P5R7:U100"]
V1.2-H0.5-P5R6 | body_imu | sensor | 身体姿态反馈 | 1 | piece | TDK ICM-42688-P / MORI_imu_P5R4 daughterboard | P5R4 | 3.3V VDD/VDDIO; SPI1 initial6MHz, ODR1000Hz/DRDY timestamp target | SPI + DRDY/采集时间戳 | ["HW12-ICM", "HW12-PCB"] | 2026-09-22 | VENDOR_DOCUMENTED | {"chip_xy": [2.5, 3.0], "designed_board_xy": [20, 16], "board_thickness": 1.6, "installed_height": null} |  |  |  |  | ["body_imu"] | False |  |  |  | CNY |  | UNKNOWN |  | UNKNOWN | UNKNOWN；国内运费另列，不假设包邮 | BLOCKED | PROTOTYPE_DISCRETE_IMU_BOARD |  |  | 更换须重核供电、协议、包络、重量与成本；未授权自行改主路线 | ["最新量产手册/封装确认", "国内芯片报价与SMT打样", "轴向装配确认与数据延迟实测"] | 本行只计ICM芯片；PCB、无源器件及贴装另列，不把整个子板与散件重复计价。LGA需回流服务，现有万用表/限流电源不是贴装设备。 |  |  | UNCONFIRMED |  |  | ["MORI_imu_P5R4:U1"]
V1.2-H0.5-P5R6 | interaction_cam | controller | 头内交互主控、摄像头及板载音频 | 1 | piece | Waveshare ESP32-S3-CAM-OV3660 / SKU33700 |  | 系统稳压5 V输入；单节BAT口严禁接3S | ESP32-S3R8 16MB Flash/8MB PSRAM；OV3660 DVP；LCD QSPI；板载音频 | ["HW12-W1", "HW12-W2", "HW12-MECH-CAM33700_DRAWING"] | 2026-09-22 | VENDOR_DOCUMENTED | {"board_width_mm": 37, "board_height_mm": 37, "mount_center_pitch_mm": [32.6, 32.6], "corner_radius_mm": 2.25, "hole_edge_offset_mm": 2.2, "mount_hole_diameter_mm": null, "pcb_thickness_mm": null, "populated_total_depth_mm": null, "usb_projection_mm": null, "microphone_coordinates_mm": null, "antenna_coordinates_mm": null, "mechanical_notes": "Board outline37x37, outer cornerR2.25 and four hole-center grid32.6x32.6 verified from official dimension image. Hole diameter, populated thickness, exact connector/mic/antenna positions are NOT documented. Y12mm remains clearly amber ALLOCATION ONLY; never reported as actual board thickness. No final CAM mount-hole diameter."} |  |  |  |  | ["cam_board"] | False |  |  |  | CNY |  | UNKNOWN |  | UNKNOWN | UNKNOWN；国内运费另列，不假设包邮 | BLOCKED | PRIMARY_SPECIFIED_NOT_RELEASED |  |  | 更换须重核供电、协议、包络、重量与成本；未授权自行改主路线 | ["完整安装高度/孔径/净重/连接器麦克风天线位置", "DVP原装排线长度/接触面", "具体OV3660版国内价格", "相机+屏+音频压力测试"] | J11 UART与TF卡复用，首轮禁TF；CH32V003F4U6为板载I/O扩展辅助MCU。 |  |  | UNCONFIRMED |  |  |  | [{"model": "OV3660", "quantity": 1, "role": "camera"}, {"model": "MEMS microphone", "quantity": 2, "role": "microphone"}, {"model": "ES7210", "quantity": 1, "role": "audio_adc"}, {"model": "ES8311", "quantity": 1, "role": "codec"}, {"model": "NS4150B", "quantity": 1, "role": "speaker_amplifier"}, {"model": "CH32V003F4U6", "quantity": 1, "role": "io_expander_not_application_mcu"}]
V1.2-H0.5-P5R6 | display | display | 黑底双眼圆屏 | 1 | piece | Waveshare 1.85inch Touch LCD Module / SKU35079 |  | 3.3/5 V模块输入；360×360；ST77916/CST816S | QSPI + I2C；18P FFC或15P端子 | ["HW12-W3", "HW12-MECH-LCD35079_STEP"] | 2026-09-22 | VENDOR_DOCUMENTED | {"glass_outer_diameter_mm": 55, "active_diameter_mm": 45.68, "view_diameter_mm": 46.08, "glass_thickness_mm": 0.7, "pcb_thickness_mm": 1.6, "drawing_reference_total_depth_mm": 9.1, "cad_total_depth_mm": 9.3500001, "mount_thread": "3xM2", "drawing_hole_xz_from_screen_mm": [[0, 21], [-14.85, -14.85], [14.85, -14.85]], "cad_post_center_xz_from_screen_mm": [[0, 20.94], [-14.84924240492, -14.90924240492], [14.84924240492, -14.90924240492]], "thread_engagement_approved_mm": null, "mechanical_notes": "Official Rev1 STEP is imported1:1, including populated rear PCB, connector housings and three standoffs. No loose mating plug or FFC included. PDF9.1ref vs CAD9.35 and hole centers differ by up to0.06mm: retain STEP geometry, match physical revision before final print/hole freeze. Prior55x55 full-rectangle-only conflict is superseded by actual circular CAD shape."} |  |  |  |  | ["display"] | False |  |  |  | CNY |  | UNKNOWN |  | UNKNOWN | UNKNOWN；国内运费另列，不假设包邮 | BLOCKED | PRIMARY_SPECIFIED_NOT_RELEASED |  |  | 更换须重核供电、协议、包络、重量与成本；未授权自行改主路线 | ["采购Rev1对应/净重", "STEP9.35与PDF9.1ref差异、孔位约0.06mm差异", "排线接触面/插拔净空与16–18脚定义", "所选SKU国内价格"] | 替代旧H0.3的TDO2.1寸主选；显示跨度由53.28改45.68mm，按V1.2执行。 |  |  | UNCONFIRMED
V1.2-H0.5-P5R6 | speaker | audio | 身体扬声器与音腔 | 1 | piece | WSS-SP3040-08 / YH-SP3040-08 | WSSSZ201809110016 / 1.0 | 4 ohm / 3 W nominal; 3.5 W max per supplied SP3040 specification | NS4150B BTL J5，两线均不能接公共地 | ["SP3040_USER_SPEC"] | 2026-10-07 | ASSUMED | {"box_width_height_depth": [42, 30, 9], "overall_ear_span": 56, "mount_hole_pitch": 49} |  |  |  |  | ["speaker"] | False |  |  |  | CNY |  | UNKNOWN |  | UNKNOWN | UNKNOWN；国内运费另列，不假设包邮 | BLOCKED | USER_SELECTED_UNMEASURED |  |  | 更换须重核供电、协议、包络、重量与成本；未授权自行改主路线 | ["实物耳厚、孔径解释、公差与安装配合", "质量、国内价格与库存", "声学/热与功放适配测试"] | User selected the supplied SP3040. Per-field evidence and approved estimates: config/geometry.json#/detail_fit/speaker/field_evidence. Unknown ear details remain ASSUMED; no procurement/physical release. |  |  | UNCONFIRMED
V1.2-H0.5-P5R6 | battery | power | 成品主电池 | 1 | piece | 成品3S 2200–2600mAh电池组（未选定） |  | 化学体系、额定/满充/截止/放电能力待选 | 保护/均衡/温度/插头分别核对 | ["HW12-SPEC"] | 2026-09-22 | ASSUMED |  |  |  |  |  | ["battery"] | False |  |  |  | CNY |  | UNKNOWN |  | UNKNOWN | UNKNOWN；国内运费另列，不假设包邮 | BLOCKED | REQUIRED_UNSELECTED |  |  | 更换须重核供电、协议、包络、重量与成本；未授权自行改主路线 | ["型号/化学体系/厂家", "尺寸/重量/电流/保护/温度", "国内现货价格"] | 若4.2V/cell，满充12.6V与S288上限重合；不焊裸电芯。 |  |  | UNCONFIRMED
V1.2-H0.5-P5R6 | battery_protection | power | 电池保护/均衡/温度 | 1 | set | 与成品3S匹配方案；随包则合并价格，当前未知 |  | 具体额定与采购规格未冻结 | 保护不等于充电或电源路径 | ["HW12-SPEC"] | 2026-09-22 | ASSUMED |  |  |  |  |  | [] | False |  |  |  | CNY |  | UNKNOWN |  | UNKNOWN | UNKNOWN；国内运费另列，不假设包邮 | BLOCKED | REQUIRED_UNSELECTED |  |  | 更换须重核供电、协议、包络、重量与成本；未授权自行改主路线 | ["精确型号/价格/现货或加工报价", "相关额定、包络与连接器"] |  |  |  | UNCONFIRMED
V1.2-H0.5-P5R6 | usb_charge | power | USB-C及3S CC/CV充电 | 1 | set | UNSELECTED finished3S USB-C CC/CV module |  | 具体额定与采购规格未冻结 | 不沿用BQ25887或CAM单节充电 | ["HW12-IP2326", "HW12-SPEC"] | 2026-09-22 | ASSUMED |  |  |  |  |  | [] | False |  |  |  | CNY |  | UNKNOWN |  | UNKNOWN | UNKNOWN；国内运费另列，不假设包邮 | BLOCKED | REQUIRED_UNSELECTED |  |  | 更换须重核供电、协议、包络、重量与成本；未授权自行改主路线 | ["确切模块型号/修订/原理图/尺寸", "CC advertisement/input limit and ordinary5V behavior", "3S voltage accuracy/current/NTC and pack balance", "国内报价"] | 后部P4仅提供USB-C、CC/ESD/保险和开关接口；外部3S充电/PD/温度/电源路径模块仍未选定，不能据接口PCB称充电完整。 |  |  | UNCONFIRMED
V1.2-H0.5-P5R6 | wheel_power | power | 轮驱母线保护与回灌 | 1 | set | Pololu D36V50F9 #4094 9V buck (engineering reference) |  | 9V5A typical,9.9–50Vinput; actual curve/thermal limit required | 满电制动及BMS断开必须处理；TVS单独不够 | ["HW12-POL9"] | 2026-09-22 | ASSUMED | {"xyz": [25.4, 25.4, 9.525]} | 7 |  |  |  | [] | False |  |  |  | CNY |  | UNKNOWN |  | UNKNOWN | UNKNOWN；国内运费另列，不假设包邮 | BLOCKED | ENGINEERING_REFERENCE_CN_QUOTE_PENDING |  |  | 更换须重核供电、协议、包络、重量与成本；未授权自行改主路线 | ["精确型号/价格/现货或加工报价", "相关额定、包络与连接器"] | P1 adds B540C blocking, switched output and rail-powered brake on separate power PCB. Do not mistake D24V50F9 for a real selected part. |  |  | UNCONFIRMED
V1.2-H0.5-P5R6 | head_power | power | 独立6V支路 | 1 | set | Pololu D24V22F6 #2859 |  | 6V nominal; output after blocking diode estimated5.21–6.04V | 按两SCS0009并发连续与峰值核额定 | ["HW12-POL6"] | 2026-09-22 | ASSUMED | {"xyz": [17.8, 17.8, 8]} | 2.3 |  |  |  | [] | False |  |  |  | CNY |  | UNKNOWN |  | UNKNOWN | UNKNOWN；国内运费另列，不假设包邮 | BLOCKED | ENGINEERING_REFERENCE_CN_QUOTE_PENDING |  |  | 更换须重核供电、协议、包络、重量与成本；未授权自行改主路线 | ["精确型号/价格/现货或加工报价", "相关额定、包络与连接器"] | Use4.8V head rated torque for conservative check; not a6V guarantee at servo pins. |  |  | UNCONFIRMED
V1.2-H0.5-P5R6 | logic_power | power | 运动/交互板载5V降压IC（两个独立支路） | 2 | set | TPS54302DDCR | P4 routed prototype; S3 buck circuit retained | 4.5-28V input;400kHz;chip3A; system targets0.5A motion/1.5A CAM sustained | Board-local3S-to5V; MCU modules retain their own3.3V. No separate Pololu5V modules. | ["HW12-S3-02"] | 2026-09-22 | VENDOR_DOCUMENTED | {"package_envelope_xyz": [2.9, 2.8, 1.1], "note": "TI DDC0006A IC envelope only; not a converter-module or board envelope. H1.1max."} |  |  |  |  | [] | False | 立创商城 | C311983 / TPS54302DDCR |  | CNY |  | UNKNOWN |  | UNKNOWN | UNKNOWN；国内运费另列，不假设包邮 | CN_CATALOG_FOUND_QUOTE_PENDING | SELECTED_ROUTED_PROTOTYPE_NOT_BENCH_VALIDATED |  |  | 更换须重核供电、协议、包络、重量与成本；未授权自行改主路线 | ["国内小批量结算价/库存", "实际模块并发电流", "纹波/瞬态/温升实测", "实际铜厚/纹波/瞬态/温升台架验证"] | Replaces the unpurchased Pololu D24V22F5 x2. No old module mass/envelope is reused. U60/U70. SLVSDG6C Rev C. 1GND 2SW 3VIN 4FB 5EN 6BOOT. EN internally pulled up; never tie EN to 3S VIN. 3A silicon rating is not the qualified harness/assembly rating. |  |  | UNCONFIRMED |  |  | ["MORI_power_P5R6:U60", "MORI_power_P5R6:U70"]
V1.2-H0.5-P5R6 | lcd_cable | interface | 屏幕FFC及必要转接 | 1 | set | Waveshare LCD35079 supplied FFC18P 0.5mm 200mm same-side contacts |  | 具体额定与采购规格未冻结 | CAM端TE未接；同针数不是插接批准 | ["HW12-SPEC"] | 2026-09-22 | ASSUMED | {"pitch": 0.5, "positions": 18, "length": 200} |  |  |  |  | [] | False |  |  |  | CNY |  | UNKNOWN |  | UNKNOWN | UNKNOWN；国内运费另列，不假设包邮 | BLOCKED | VENDOR_PACKING_LIST; ASSEMBLY_DIRECTION_NOT_TESTED |  |  | 更换须重核供电、协议、包络、重量与成本；未授权自行改主路线 | ["精确型号/价格/现货或加工报价", "相关额定、包络与连接器"] | Included in display package if actual order confirms; not counted as free without quote. Reconcile CAM connector mating orientation by continuity before energizing. |  |  | UNCONFIRMED
V1.2-H0.5-P5R6 | user_button | control | 已移除的外部功能按钮（保留历史条目） | 0 | set | C&K PTS645SL50SMTR92LFS candidate + printed cap |  | 具体额定与采购规格未冻结 | normally-open dry contact to motion J6 /PC13; no MCU reset | ["HW12-SPEC"] | 2026-09-22 | ASSUMED |  |  |  |  |  | [] | False |  |  |  | CNY |  | UNKNOWN |  | UNKNOWN | UNKNOWN；国内运费另列，不假设包邮 | NOT_APPLICABLE | NOT_APPLICABLE |  |  | 更换须重核供电、协议、包络、重量与成本；未授权自行改主路线 | ["精确型号/价格/现货或加工报价", "相关额定、包络与连接器"] | M1.11明确移除独立外壳按钮；运动J6仅保留机内PC13维护输入，非RESET。未额外购买C&K按钮。 |  |  | NOT_APPLICABLE
V1.2-H0.5-P5R6 | physical_disable | control | 后接口板双刀物理电源/禁驱开关 | 1 | piece | SOFNG MS-202V-G3 | P5 | 0.5A/30VDC catalog rating; low-current contacts only | rear SW1; pole A controls power Q90 via10k, pole B opens motion J8 latch-clear loop | ["HW12-P4-CONNECTORS"] | 2026-09-22 | VENDOR_DOCUMENTED | {"body_xyz": [9.1, 3.5, 3.5], "stem_mm": 3, "travel_mm": 2, "installed_envelope": "See hardware/v1_2/handoff/mechanical_P4.json"} |  |  |  |  | [] | False | https://item.szlcsc.com/44278924.html | C42378287 / MS-202V-G3 |  | CNY |  | UNKNOWN |  | UNKNOWN | UNKNOWN；国内运费另列，不假设包邮 | CN_CATALOG_FOUND_QUOTE_PENDING | REQUIRED_UNSELECTED |  |  | 更换须重核供电、协议、包络、重量与成本；未授权自行改主路线 | ["样品万用表确认双刀状态/本地编号", "国内结算报价", "操作机构/外壳适配", "Q90浪涌/SOA/温升"] | 主电流通过电源板Q90/Q1；小开关不承载电机电流。OFF会失去平衡；托架使用。故障恢复不得自动ARM。 |  |  | UNCONFIRMED |  |  | ["MORI_rear_P5R7:SW1"]
V1.2-H0.5-P5R6 | tyres | mechanical | 轮胎 | 2 | piece | Ø105×18轮胎/胎圈（机械要求，具体商品未选） |  | 具体额定与采购规格未冻结 | 按实际轮径算速度，抓地/重量待验 | ["HW12-SPEC"] | 2026-09-22 | ASSUMED | {"mechanical_requirement_diameter": 105, "mechanical_requirement_width": 18, "vendor_envelope": null} |  |  |  |  | [] | False |  |  |  | CNY |  | UNKNOWN |  | UNKNOWN | UNKNOWN；国内运费另列，不假设包邮 | BLOCKED | REQUIRED_UNSELECTED |  |  | 更换须重核供电、协议、包络、重量与成本；未授权自行改主路线 | ["精确型号/价格/现货或加工报价", "相关额定、包络与连接器"] | 以当前config/geometry.json为机械尺寸来源；不是已核商品尺寸。不得采购旧Ø95胎后缩放硬件模型。 |  |  | UNCONFIRMED
V1.2-H0.5-P5R6 | wheel_couplers | mechanical | 轮毂/轮轴/输出连接 | 2 | piece | M1.14 custom metal flanged shaft / double-D hub interface, candidate |  | 具体额定与采购规格未冻结 | 不把径向外力全部施加到舵机细轴 | ["HW12-SPEC"] | 2026-09-22 | ASSUMED |  |  |  |  |  | [] | False |  |  |  | CNY |  | UNKNOWN |  | UNKNOWN | UNKNOWN；国内运费另列，不假设包邮 | BLOCKED | REQUIRED_UNSELECTED |  |  | 更换须重核供电、协议、包络、重量与成本；未授权自行改主路线 | ["精确型号/价格/现货或加工报价", "相关额定、包络与连接器"] | 继承当前mechanical wheel_interface设计；两根定制钢轴/隔套及接口报价未取得，不是现成已购件。加工、公差、输出小孔螺钉、同轴度、强度与载荷试验尚未通过。 |  |  | UNCONFIRMED
V1.2-H0.5-P5R6 | wheel_bearings | mechanical | 轮轴承 | 4 | piece | 686ZZ candidate; exact manufacturer/order suffix pending |  | M1.14/M1.15 wheel interface requires two686ZZ per wheel,6x13x5mm | 两轴各两支撑的当前设计数量，型号/载荷待核 | ["HW12-SPEC"] | 2026-09-22 | ASSUMED | {"mechanical_required_ID_OD_width": [6.0, 13.0, 5.0], "selected_vendor_confirmed": false} |  |  |  |  | [] | False |  |  |  | CNY |  | UNKNOWN |  | UNKNOWN | UNKNOWN；国内运费另列，不假设包邮 | BLOCKED | REQUIRED_UNSELECTED |  |  | 更换须重核供电、协议、包络、重量与成本；未授权自行改主路线 | ["精确型号/价格/现货或加工报价", "相关额定、包络与连接器"] | 替换旧4ID/10OD/4W占位要求；机械方案是尺寸需求，非本次实物/供应商确认。 |  |  | UNCONFIRMED
V1.2-H0.5-P5R6 | head_bearings | mechanical | 头承载轴承套件 | 1 | set | Yaw 6806ZZ 30x42x7; bilateral pitch 5x12x4 reference |  | M1.49 adopted yaw 6806ZZ 30x42x7 mm; keep the current pitch reference | 具体型号/数量/公差按机械确认 | ["HW12-SPEC"] | 2026-09-22 | ASSUMED | {"yaw_ID_OD_width": [30, 42, 7], "pitch_ID_OD_width": [5, 12, 4]} |  |  |  |  | [] | False |  |  |  | CNY |  | UNKNOWN |  | UNKNOWN | UNKNOWN；国内运费另列，不假设包邮 | BLOCKED | MECHANICAL_NOMINAL_ADOPTED_PHYSICAL_FIT_PENDING |  |  | 更换须重核供电、协议、包络、重量与成本；未授权自行改主路线 | ["精确型号/价格/现货或加工报价", "相关额定、包络与连接器"] | Mechanical receipt: config/geometry.json#/neck_harness_capacity. Manufacturer/order suffix, actual fits, loads and price remain unqualified. |  |  | UNCONFIRMED
V1.2-H0.5-P5R6 | carrier_pcb | fabrication | 一次基础PCB打样 | 1 | four-board prototype set | MORI_motion_P5R7 + MORI_imu_P5R4 + MORI_power_P5R6 + MORI_rear_P5R7 | motion/power/rear:P5R6; imu:P5R4 | motion70x35 four-layer; power80x55 four-layer70/35/35/70um nominal; IMU20x16 and rear24x25 two-layer; all1.6mm; supplier stack-up and quote pending | Native geometry: hardware/v1_2/handoff/mechanical_P5R6.json | ["HW12-PCB"] | 2026-09-22 | ASSUMED | {"motion_xy": [70, 35], "imu_xy": [20, 16], "power_xy": [80, 55], "board_thickness": 1.6, "power_thickness": 1.6, "full_installed_height": null} |  |  |  |  | [] | False |  |  |  | CNY |  | UNKNOWN |  | UNKNOWN | UNKNOWN；国内运费另列，不假设包邮 | BLOCKED | ROUTED_PROTOTYPE_NOT_RELEASED |  |  | 更换须重核供电、协议、包络、重量与成本；未授权自行改主路线 | ["四板打样/贴装/铜厚的国内报价", "完整机械插合包络", "实机验证"] | P5原型四板。电源由2层升级4层以保证公共地回流；旧打样额度不是新叠层报价。完整插合尺寸与物理验证仍未完成。 |  |  | UNCONFIRMED
V1.2-H0.5-P5R6 | harness | assembly | 高电流/跨轴/维护线束 | 1 | set | 额定线规/防呆端子/压接/应力释放待选 |  | 具体额定与采购规格未冻结 | 大电流不走杜邦、面包板或显示FFC | ["HW12-SPEC"] | 2026-09-22 | ASSUMED |  |  |  |  |  | [] | False |  |  |  | CNY |  | UNKNOWN |  | UNKNOWN | UNKNOWN；国内运费另列，不假设包邮 | BLOCKED | REQUIRED_UNSELECTED |  |  | 更换须重核供电、协议、包络、重量与成本；未授权自行改主路线 | ["精确型号/价格/现货或加工报价", "相关额定、包络与连接器"] | 按P4逐针线束表制作；线长及弯曲待机械交接。PH配对壳/端子单列，线材、XT30/XH对端、工厂转接及压接加工仍包含在本项，未免除费用。 |  |  | UNCONFIRMED
V1.2-H0.5-P5R6 | fasteners | assembly | 紧固件/嵌件 | 1 | set | 机械装机套件待核量 |  | 具体额定与采购规格未冻结 | 不假定已有 | ["HW12-SPEC"] | 2026-09-22 | ASSUMED |  |  |  |  |  | [] | False |  |  |  | CNY |  | UNKNOWN |  | UNKNOWN | UNKNOWN；国内运费另列，不假设包邮 | BLOCKED | REQUIRED_UNSELECTED |  |  | 更换须重核供电、协议、包络、重量与成本；未授权自行改主路线 | ["精确型号/价格/现货或加工报价", "相关额定、包络与连接器"] |  |  |  | UNCONFIRMED
V1.2-H0.5-P5R6 | printing | fabrication | 外壳/支架/托架打印材料 | 1 | set | 按机械体积/填充/损耗核量 |  | 具体额定与采购规格未冻结 | 含必需维护托架和基础试打材料 | ["HW12-SPEC"] | 2026-09-22 | ASSUMED |  |  |  |  |  | [] | False |  |  |  | CNY |  | UNKNOWN |  | UNKNOWN | UNKNOWN；国内运费另列，不假设包邮 | BLOCKED | REQUIRED_UNSELECTED |  |  | 更换须重核供电、协议、包络、重量与成本；未授权自行改主路线 | ["精确型号/价格/现货或加工报价", "相关额定、包络与连接器"] |  |  |  | UNCONFIRMED
V1.2-H0.5-P5R6 | shipping | logistics | 国内运费 | 1 | set | 实际店铺合单/地址结算待核 |  | 具体额定与采购规格未冻结 | 不假设包邮或运费券 | ["HW12-SPEC"] | 2026-09-22 | ASSUMED |  |  |  |  |  | [] | False |  |  |  | CNY |  | UNKNOWN |  | UNKNOWN | UNKNOWN；国内运费另列，不假设包邮 | BLOCKED | REQUIRED_UNSELECTED |  |  | 更换须重核供电、协议、包络、重量与成本；未授权自行改主路线 | ["精确型号/价格/现货或加工报价", "相关额定、包络与连接器"] |  |  |  | UNCONFIRMED
V1.2-H0.5-P5R6 | usb_adapter | power | External USB-C adapter matched to charger input profile | 1 | set | UNSELECTED: dependent on qualified3S charger |  | 具体额定与采购规格未冻结 | 不沿用BQ25887或CAM单节充电 | ["HW12-IP2326", "HW12-SPEC"] | 2026-09-22 | ASSUMED |  |  |  |  |  | [] | False |  |  |  | CNY |  | UNKNOWN |  | UNKNOWN | UNKNOWN；国内运费另列，不假设包邮 | BLOCKED | BLOCKED_CHARGER_SELECTION |  |  | 更换须重核供电、协议、包络、重量与成本；未授权自行改主路线 | ["确切模块型号/修订/原理图/尺寸", "CC advertisement/input limit and ordinary5V behavior", "3S voltage accuracy/current/NTC and pack balance", "国内报价"] | User owns no components; mandatory accessory cost retained as UNKNOWN, not zero. |  |  | UNCONFIRMED
V1.2-H0.5-P5R6 | usb_charge_cable | power | USB-C charging cable matched to current/CC/PD profile | 1 | set | UNSELECTED: dependent on qualified3S charger |  | 具体额定与采购规格未冻结 | 不沿用BQ25887或CAM单节充电 | ["HW12-IP2326", "HW12-SPEC"] | 2026-09-22 | ASSUMED |  |  |  |  |  | [] | False |  |  |  | CNY |  | UNKNOWN |  | UNKNOWN | UNKNOWN；国内运费另列，不假设包邮 | BLOCKED | BLOCKED_CHARGER_SELECTION |  |  | 更换须重核供电、协议、包络、重量与成本；未授权自行改主路线 | ["确切模块型号/修订/原理图/尺寸", "CC advertisement/input limit and ordinary5V behavior", "3S voltage accuracy/current/NTC and pack balance", "国内报价"] | User owns no components; mandatory accessory cost retained as UNKNOWN, not zero. |  |  | UNCONFIRMED
V1.2-H0.5-P5R6 | p1_dump_wheel | power | wheel制动外置功率电阻 | 1 | set | Vishay AC05000005608JAC00 candidate |  | 5.6ohm5W; pulse energy NOT_QUALIFIED | 大电流不走杜邦、面包板或显示FFC | ["HW12-PCB"] | 2026-09-22 | ASSUMED |  |  |  |  |  | [] | False |  |  |  | CNY |  | UNKNOWN |  | UNKNOWN | UNKNOWN；国内运费另列，不假设包邮 | BLOCKED | PULSE_CURVE_AND_CN_QUOTE_PENDING |  |  | 更换须重核供电、协议、包络、重量与成本；未授权自行改主路线 | ["精确型号/价格/现货或加工报价", "相关额定、包络与连接器"] | Do not substitute5W nameplate for20W wheel pulse capability. Heat isolation and mounting external to crowded PCB required. |  |  | UNCONFIRMED
V1.2-H0.5-P5R6 | p1_dump_head | power | head制动外置功率电阻 | 1 | set | Vishay AC05000001009JAC00 candidate |  | 10ohm5W; pulse energy NOT_QUALIFIED | 大电流不走杜邦、面包板或显示FFC | ["HW12-PCB"] | 2026-09-22 | ASSUMED |  |  |  |  |  | [] | False |  |  |  | CNY |  | UNKNOWN |  | UNKNOWN | UNKNOWN；国内运费另列，不假设包邮 | BLOCKED | PULSE_CURVE_AND_CN_QUOTE_PENDING |  |  | 更换须重核供电、协议、包络、重量与成本；未授权自行改主路线 | ["精确型号/价格/现货或加工报价", "相关额定、包络与连接器"] | Do not substitute5W nameplate for20W wheel pulse capability. Heat isolation and mounting external to crowded PCB required. |  |  | UNCONFIRMED
V1.2-H0.5-P5R6 | p4_001 | pcb_part | P4 PCB装配：MORI_power_P5R6:F60 | 1 | piece | 0451001.MRL | P5 | 1A / 125V / very fast | Fuse:Fuse_Littelfuse-NANO2-451_453 | ["HW12-S3-01"] | 2026-09-23 | ASSUMED |  |  |  |  |  | [] | False | 立创商城/授权分销，精确SKU待核价 | C3099 |  | CNY |  | NOT_LIVE_CHECKOUT_CONFIRMED |  | UNKNOWN | 国内运费另列；未确认包邮 | EXACT_QUOTE_PENDING | SELECTED_SCHEMATIC_ONLY |  |  | 额定、引脚、封装、反馈公差和环路稳定性重新核对 | ["国内精确MPN小批量报价/库存", "封装与布局终审", "实板测试"] | Input branch fuse, not a fast electronic current limiter. Coordinate inrush, ambient derating and upstream 6.3A fuse on bench. |  |  | UNCONFIRMED |  |  | ["MORI_power_P5R6:F60"]
V1.2-H0.5-P5R6 | p4_002 | pcb_part | P4 PCB装配：MORI_power_P5R6:F70 | 1 | piece | 0451002.MRL | P5 | 2A / 125V / very fast | Fuse:Fuse_Littelfuse-NANO2-451_453 | ["HW12-S3-11"] | 2026-09-23 | ASSUMED |  |  |  |  |  | [] | False | 立创商城/授权分销，精确SKU待核价 | C99547 |  | CNY |  | NOT_LIVE_CHECKOUT_CONFIRMED |  | UNKNOWN | 国内运费另列；未确认包邮 | EXACT_QUOTE_PENDING | SELECTED_SCHEMATIC_ONLY |  |  | 额定、引脚、封装、反馈公差和环路稳定性重新核对 | ["国内精确MPN小批量报价/库存", "封装与布局终审", "实板测试"] | Input branch fuse, not a fast electronic current limiter. Coordinate inrush, ambient derating and upstream 6.3A fuse on bench. |  |  | UNCONFIRMED |  |  | ["MORI_power_P5R6:F70"]
V1.2-H0.5-P5R6 | p4_003 | pcb_part | P4 PCB装配：MORI_rear_P5R7:F1 | 1 | piece | 045101.5MRL | P5 | 045101.5MRL / 1.5A | MORI_Custom:Littelfuse_451_6.1x2.69_P4__P3R1_F1 | ["HW12-P4"] | 2026-09-23 | ASSUMED |  |  |  | MORI_Custom:Littelfuse_451_6.1x2.69_P4__P3R1_F1 |  | [] | False | 立创商城/淘宝授权店；未形成所选SKU结算证据 | 045101.5MRL |  | CNY |  | NOT_LIVE_CONFIRMED |  | UNKNOWN | UNKNOWN；国内运费另列，不假设包邮 | BLOCKED_QUOTE_AND_ASSEMBLY | PROTOTYPE_SELECTED_NOT_PURCHASED |  |  | 封装/引脚/额定/公差不等同则重新适配 | ["国内精确SKU结算报价与库存", "实物/装配及电气验证"] | P4原生工程对应的器件；不能视为整机已核价。 |  |  | UNCONFIRMED |  |  | ["MORI_rear_P5R7:F1"] |  | ["https://www.littelfuse.com/assetdocs/fuse-451-and-453-datasheet?assetguid=533cd5cc-956c-4243-867f-6ab5a62f6ba1"] | []
V1.2-H0.5-P5R6 | p4_004 | pcb_part | P4 PCB装配：MORI_power_P5R6:JP60, MORI_power_P5R6:JP70 | 2 | piece | 61300211121 | P5 | SERVICE OFF / OPEN=ON | MORI_Custom:PinHeader_1x02_P2.54mm_Vertical__P3R1_JP70; MORI_Custom:PinHeader_1x02_P2.54mm_Vertical__P3_JP60__P3R1_JP60 | ["HW12-S3-10"] | 2026-09-23 | ASSUMED |  |  |  |  |  | [] | False | 立创商城/授权分销，精确SKU待核价 | 61300211121 |  | CNY |  | NOT_LIVE_CHECKOUT_CONFIRMED |  | UNKNOWN | 国内运费另列；未确认包邮 | EXACT_QUOTE_PENDING | SELECTED_SCHEMATIC_ONLY |  |  | 额定、引脚、封装、反馈公差和环路稳定性重新核对 | ["国内精确MPN小批量报价/库存", "封装与布局终审", "实板测试"] | Normally open header. Bridge 1-2 only in maintenance cradle to disable this one rail. Motion supply loss removes ARM and robot balance. No automatic MCU-controlled power cycling. |  |  | UNCONFIRMED |  |  | ["MORI_power_P5R6:JP60", "MORI_power_P5R6:JP70"]
V1.2-H0.5-P5R6 | p4_005 | pcb_part | P4 PCB装配：MORI_power_P5R6:J1, MORI_power_P5R6:J2, MORI_power_P5R6:J3, MORI_power_P5R6:J4, MORI_power_P5R6:J5, MORI_power_P5R6:J11, MORI_power_P5R6:J12 | 7 | piece | AMASS XT30UPB-M | P5 | HEAD BUCK 6V RETURN; HEAD BUCK VIN; HEAD DUMP 10R EXTERNAL; PACK AFTER 6.3A FUSE; WHEEL BUCK 9V RETURN; WHEEL BUCK VIN; WHEEL DUMP 5R6 EXTERNAL | Connector_AMASS:AMASS_XT30UPB-M_1x02_P5.0mm_Vertical; MORI_Custom:AMASS_XT30UPB-M_1x02_P5.0mm_Vertical__P2_J12__P3R1_J12; MORI_Custom:AMASS_XT30UPB-M_1x02_P5.0mm_Vertical__P2_J4__P3_J4__P3R1_J4; MORI_Custom:AMASS_XT30UPB-M_1x02_P5.0mm_Vertical__P2_J5__P3_J5; MORI_Custom:AMASS_XT30UPB-M_1x02_P5.0mm_Vertical__P3R1_J3; MORI_Custom:AMASS_XT30UPB-M_1x02_P5.0mm_Vertical__P3_J1; MORI_Custom:AMASS_XT30UPB-M_1x02_P5.0mm_Vertical__P3_J2__P3R1_J2 | ["HW12-PCB"] | 2026-09-23 | ASSUMED | {"package_footprint": "Connector_AMASS:AMASS_XT30UPB-M_1x02_P5.0mm_Vertical"} |  |  | Connector_AMASS:AMASS_XT30UPB-M_1x02_P5.0mm_Vertical |  | [] | False | 立创商城/淘宝授权店；未形成所选SKU结算证据 | AMASS XT30UPB-M |  | CNY |  | UNKNOWN |  | UNKNOWN | UNKNOWN；国内运费另列，不假设包邮 | BLOCKED_QUOTE_AND_ASSEMBLY | KICAD_LIBRARY_FOOTPRINT; MATCH_VENDOR_AND_MATE |  |  | 封装/引脚/额定/公差不等同则重新适配 | ["国内精确MPN小批量价格、库存、税运"] | Native schematic/PCB BOM cross-reference; not a quote and not purchased.; J6 marked DNP in S3; previous P2 physical board remains unchanged. |  |  | UNCONFIRMED |  |  | ["MORI_power_P5R6:J1", "MORI_power_P5R6:J2", "MORI_power_P5R6:J3", "MORI_power_P5R6:J4", "MORI_power_P5R6:J5", "MORI_power_P5R6:J11", "MORI_power_P5R6:J12"]
V1.2-H0.5-P5R6 | p4_006 | pcb_part | P4 PCB装配：MORI_power_P5R6:Q11, MORI_power_P5R6:Q31, MORI_power_P5R6:Q20, MORI_power_P5R6:Q40 | 4 | piece | AO3400A | P5 | AO3400A | Package_TO_SOT_SMD:SOT-23 | ["HW12-AOS-ao3400a"] | 2026-09-23 | VENDOR_DOCUMENTED | {"package_footprint": "Package_TO_SOT_SMD:SOT-23"} |  |  | Package_TO_SOT_SMD:SOT-23 |  | [] | False | 立创商城/淘宝授权店；未形成所选SKU结算证据 | AO3400A |  | CNY |  | UNKNOWN |  | UNKNOWN | UNKNOWN；国内运费另列，不假设包邮 | BLOCKED_QUOTE_AND_ASSEMBLY | EXACT_IC_VENDOR_PINMAP; CN_QUOTE_PENDING |  |  | 封装/引脚/额定/公差不等同则重新适配 | ["国内精确MPN小批量价格、库存、税运"] | Native schematic/PCB BOM cross-reference; not a quote and not purchased. |  |  | UNCONFIRMED |  |  | ["MORI_power_P5R6:Q11", "MORI_power_P5R6:Q31", "MORI_power_P5R6:Q20", "MORI_power_P5R6:Q40"]
V1.2-H0.5-P5R6 | p4_007 | pcb_part | P4 PCB装配：MORI_power_P5R6:Q1, MORI_power_P5R6:Q10, MORI_power_P5R6:Q30, MORI_power_P5R6:Q90 | 4 | piece | AO4407A | P5 | AO4407A | Package_SO:SOIC-8_3.9x4.9mm_P1.27mm | ["HW12-AOS-ao4407a"] | 2026-09-23 | VENDOR_DOCUMENTED | {"package_footprint": "Package_SO:SOIC-8_3.9x4.9mm_P1.27mm"} |  |  | Package_SO:SOIC-8_3.9x4.9mm_P1.27mm |  | [] | False | 立创商城/淘宝授权店；未形成所选SKU结算证据 | AO4407A |  | CNY |  | UNKNOWN |  | UNKNOWN | UNKNOWN；国内运费另列，不假设包邮 | BLOCKED_QUOTE_AND_ASSEMBLY | EXACT_IC_VENDOR_PINMAP; CN_QUOTE_PENDING |  |  | 封装/引脚/额定/公差不等同则重新适配 | ["国内精确MPN小批量价格、库存、税运"] | Native schematic/PCB BOM cross-reference; not a quote and not purchased. |  |  | UNCONFIRMED |  |  | ["MORI_power_P5R6:Q1", "MORI_power_P5R6:Q10", "MORI_power_P5R6:Q30", "MORI_power_P5R6:Q90"]
V1.2-H0.5-P5R6 | p4_008 | pcb_part | P4 PCB装配：MORI_motion_P5R7:J1, MORI_motion_P5R7:J2, MORI_motion_P5R7:J6, MORI_motion_P5R7:J8, MORI_power_P5R6:J13, MORI_power_P5R6:J15, MORI_power_P5R6:J16, MORI_power_P5R6:J17, MORI_power_P5R6:J19 | 9 | piece | B2B-PH-K-S(LF)(SN) | P5 | CHARGE INTERLOCK; CHARGER RAW VBUS SENSE; INTERNAL SERVICE KEY; LATCHED ENABLE LOOP; MOTION 5V IN; MOTION 5V OUT / 1+ 2GND; REAR MASTER / 1RETURN 2GND; S288 DATA; S288 DATA ONLY | MORI_Custom:JST_PH_B2B-PH-K_1x02_P2.00mm_Vertical__P4_PH_ANNULUS; MORI_Custom:JST_PH_B2B-PH-K_1x02_P2.00mm_Vertical__P4_PH_ANNULUS__P3R1_J15; MORI_Custom:JST_PH_B2B-PH-K_1x02_P2.00mm_Vertical__P4_PH_ANNULUS__P3R1_J16; MORI_Custom:JST_PH_B2B-PH-K_1x02_P2.00mm_Vertical__P4_PH_ANNULUS__P3R1_J19 | ["HW12-P4-CONNECTORS"] | 2026-09-23 | VENDOR_DOCUMENTED | {"bare_xyz": [5.9, 4.5, 6], "mated_height": 8, "mated_depth": null, "wire_bend": null} |  |  | MORI_Custom:JST_PH_B2B-PH-K_1x02_P2.00mm_Vertical__P4_PH_ANNULUS; MORI_Custom:JST_PH_B2B-PH-K_1x02_P2.00mm_Vertical__P4_PH_ANNULUS__P3R1_J15; MORI_Custom:JST_PH_B2B-PH-K_1x02_P2.00mm_Vertical__P4_PH_ANNULUS__P3R1_J16; MORI_Custom:JST_PH_B2B-PH-K_1x02_P2.00mm_Vertical__P4_PH_ANNULUS__P3R1_J19 |  | [] | False | https://item.szlcsc.com/142630.html | C131337 / B2B-PH-K-S(LF)(SN) |  | CNY |  | NOT_LIVE_CONFIRMED |  | UNKNOWN | UNKNOWN；国内运费另列，不假设包邮 | CN_CATALOG_FOUND_QUOTE_PENDING | PROTOTYPE_SELECTED_NOT_PURCHASED |  |  | 封装/引脚/额定/公差不等同则重新适配 | ["国内精确SKU结算报价与库存", "实物/装配及电气验证"] | 厂商尺寸与国内目录料号已记录；库存、价格、线束和安装间隙未实测。 |  |  | UNCONFIRMED |  |  | ["MORI_motion_P5R7:J1", "MORI_motion_P5R7:J2", "MORI_motion_P5R7:J6", "MORI_motion_P5R7:J8", "MORI_power_P5R6:J13", "MORI_power_P5R6:J15", "MORI_power_P5R6:J16", "MORI_power_P5R6:J17", "MORI_power_P5R6:J19"] |  | ["https://www.jst-mfg.com/product/pdf/eng/ePH.pdf"] | []
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

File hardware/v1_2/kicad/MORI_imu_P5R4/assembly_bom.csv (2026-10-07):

ref | value | footprint | source | note
U1 | ICM-42688-P | MORI_Custom:TDK_ICM42688P_LGA14_3x2p5__P2_U1__P3R1_U1 | https://www.lcsc.com/datasheet/C1850418.pdf | Prototype based on vendor DS-000347 pinout. No raw cell welding; IC requires reflow. Assembly pad review required.
J1 | BODY RIGID IMU | MORI_Custom:JST_PH_B8B-PH-K_1x08_P2.00mm_Vertical__P4_PH_ANNULUS__P5_J1 | https://www.jst-mfg.com/product/pdf/eng/ePH.pdf | P4 PH 2.0 mm. PHR-8 / SPH-002T-P0.5S. Signal pin numbering unchanged. Check both mating views; never wire by color alone.
C1 | 100n | Capacitor_SMD:C_0603_1608Metric
C2 | 2.2u | Capacitor_SMD:C_0603_1608Metric
C3 | 10n | Capacitor_SMD:C_0603_1608Metric
R1 | 33 | Resistor_SMD:R_0603_1608Metric
R2 | 10k | Resistor_SMD:R_0603_1608Metric
H1 | M2 clearance | MountingHole:MountingHole_2.2mm_M2
H2 | M2 clearance | MountingHole:MountingHole_2.2mm_M2

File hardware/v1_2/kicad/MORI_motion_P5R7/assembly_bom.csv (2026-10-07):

ref | value | footprint | source | note
U100 | WeAct STM32F412RET6 64Pin V1.1 | MORI_Custom:WeAct_F4_64Pin_V11_ECorrected_P5R7 | https://github.com/WeActStudio/WeActStudio.STM32F4_64Pin_CoreBoard | A=P1 B=P2 C=P3 D=P4 E=P5. Component side UP; all male pins DOWN from core underside. E pads shifted native X+2.54mm. Only E7 NRST is connected on carrier; other E pins NC on carrier. E8 is core3V3, not a carrier supply input. Candidate female sockets 61303021821x2 +61300821821; straight E male61300821121. Stack/mating/retention NOT_TESTED; see formal P5R7 handoff. Top SWD test access needs mechanical confirmation after changing from right-angle E header.
J1 | MOTION 5V IN | MORI_Custom:JST_PH_B2B-PH-K_1x02_P2.00mm_Vertical__P4_PH_ANNULUS__P5_J1 | https://www.jst-mfg.com/product/pdf/eng/ePH.pdf | P4 PH 2.0 mm. PHR-2 / SPH-002T-P0.5S. Signal pin numbering unchanged. Check both mating views; never wire by color alone.
J2 | S288 DATA ONLY | MORI_Custom:JST_PH_B2B-PH-K_1x02_P2.00mm_Vertical__P4_PH_ANNULUS | https://www.jst-mfg.com/product/pdf/eng/ePH.pdf | P4 PH 2.0 mm. PHR-2 / SPH-002T-P0.5S. Signal pin numbering unchanged. Check both mating views; never wire by color alone.
J3 | HEAD DATA ONLY | MORI_Custom:JST_PH_B3B-PH-K_1x03_P2.00mm_Vertical__P4_PH_ANNULUS | https://www.jst-mfg.com/product/pdf/eng/ePH.pdf | P4 PH 2.0 mm. PHR-3 / SPH-002T-P0.5S. Signal pin numbering unchanged. Check both mating views; never wire by color alone.
J4 | BODY IMU SPI | MORI_Custom:JST_PH_B8B-PH-K_1x08_P2.00mm_Vertical__P4_PH_ANNULUS__P5_J4 | https://www.jst-mfg.com/product/pdf/eng/ePH.pdf | P4 PH 2.0 mm. PHR-8 / SPH-002T-P0.5S. Signal pin numbering unchanged. Check both mating views; never wire by color alone.
J5 | CAM J11 MATCH | MORI_Custom:JST_PH_B4B-PH-K_1x04_P2.00mm_Vertical__P4_PH_ANNULUS | https://www.jst-mfg.com/product/pdf/eng/ePH.pdf | P4 PH 2.0 mm. PHR-4 / SPH-002T-P0.5S. Signal pin numbering unchanged. Check both mating views; never wire by color alone.
J6 | INTERNAL SERVICE KEY | MORI_Custom:JST_PH_B2B-PH-K_1x02_P2.00mm_Vertical__P4_PH_ANNULUS | https://www.jst-mfg.com/product/pdf/eng/ePH.pdf | P4 PH 2.0 mm. PHR-2 / SPH-002T-P0.5S. Signal pin numbering unchanged. Check both mating views; never wire by color alone.
J7 | POWER CONTROL | MORI_Custom:JST_PH_B8B-PH-K_1x08_P2.00mm_Vertical__P4_PH_ANNULUS__P3R1_J7 | https://www.jst-mfg.com/product/pdf/eng/ePH.pdf | P4 PH 2.0 mm. PHR-8 / SPH-002T-P0.5S. Signal pin numbering unchanged. Check both mating views; never wire by color alone.
J8 | LATCHED ENABLE LOOP | MORI_Custom:JST_PH_B2B-PH-K_1x02_P2.00mm_Vertical__P4_PH_ANNULUS | https://www.jst-mfg.com/product/pdf/eng/ePH.pdf | P4 PH 2.0 mm. PHR-2 / SPH-002T-P0.5S. Signal pin numbering unchanged. Check both mating views; never wire by color alone.
U1 | SN74LVC2G125DCUR | MORI_Custom:TI_DCU0008A_0p85x0p30 | https://www.ti.com/lit/ds/symlink/sn74lvc2g125.pdf | Ioff; bus input 0..5.5V. External actuator VIH/VOH not yet verified. Default no transmission.
U2 | SN74LVC2G125DCUR | MORI_Custom:TI_DCU0008A_0p85x0p30__P5_U2 | https://www.ti.com/lit/ds/symlink/sn74lvc2g125.pdf | Ioff; bus input 0..5.5V. External actuator VIH/VOH not yet verified. Default no transmission.
U3 | SN74LVC2G32DCUR | MORI_Custom:TI_DCU0008A_0p85x0p30__P5_U3 | https://www.ti.com/lit/ds/symlink/sn74lvc2g32.pdf
U4 | TXU0202DCUR | MORI_Custom:TI_DCU0008A_0p85x0p30 | https://www.ti.com/lit/ds/symlink/txu0202.pdf | VCC isolation and Ioff; J11.3 powers only translator B rail, never feeds motion regulator.
U5 | SN74LVC1G74DCUR | MORI_Custom:TI_DCU0008A_0p85x0p30__P5_U5 | https://www.ti.com/lit/ds/symlink/sn74lvc1g74.pdf | Physical loop + supervisor + faults clear latch; only a new explicit ARM rising edge re-enables.
U6 | TLV803EA29DBZR | Package_TO_SOT_SMD:SOT-23 | https://www.ti.com/lit/ds/symlink/tlv803e.pdf | 2.93V threshold,200ms reset; exact non-R/non-V pinout.
D1 | BAT54H,115 | MORI_Custom:BAT54H_SOD123F_Nexperia_20241008_P5R6 |  | Cathode pin1; pulls latch clear low, does not reset MCU on ordinary disable.
D2 | BAT54H,115 | MORI_Custom:BAT54H_SOD123F_Nexperia_20241008_P5R6 |  | Cathode pin1; pulls latch clear low, does not reset MCU on ordinary disable.
D3 | BAT54H,115 | MORI_Custom:BAT54H_SOD123F_Nexperia_20241008_P5R6 |  | Cathode pin1; pulls latch clear low, does not reset MCU on ordinary disable.
R1 | 68 | Resistor_SMD:R_0603_1608Metric
R2 | 68 | Resistor_SMD:R_0603_1608Metric
R3 | 10k | Resistor_SMD:R_0603_1608Metric
R4 | 10k | Resistor_SMD:R_0603_1608Metric
R5 | 10k | Resistor_SMD:R_0603_1608Metric
R6 | 1k | Resistor_SMD:R_0603_1608Metric
R7 | 10k | Resistor_SMD:R_0603_1608Metric
R8 | 10k | Resistor_SMD:R_0603_1608Metric
R9 | 47 | Resistor_SMD:R_0603_1608Metric
R10 | 33 | Resistor_SMD:R_0603_1608Metric
R11 | 33 | MORI_Custom:R_0603_1608Metric__P5_R11
R12 | 33 | Resistor_SMD:R_0603_1608Metric
R13 | 10k | Resistor_SMD:R_0603_1608Metric
R14 | 1k | Resistor_SMD:R_0603_1608Metric
R15 | 1k | Resistor_SMD:R_0603_1608Metric
R16 | 1k | Resistor_SMD:R_0603_1608Metric
R17 | 10k | Resistor_SMD:R_0603_1608Metric
R18 | 10k | Resistor_SMD:R_0603_1608Metric
R19 | 1k | Resistor_SMD:R_0603_1608Metric
C1 | 100n | Capacitor_SMD:C_0603_1608Metric
C2 | 100n | Capacitor_SMD:C_0603_1608Metric
C3 | 100n | MORI_Custom:C_0603_1608Metric__P5_C3
C4 | 100n | Capacitor_SMD:C_0603_1608Metric
C5 | 100n | Capacitor_SMD:C_0603_1608Metric
C6 | 100n | Capacitor_SMD:C_0603_1608Metric
C7 | 100n | Capacitor_SMD:C_0603_1608Metric
C8 | 10u | Capacitor_SMD:C_0603_1608Metric
C9 | 10n | Capacitor_SMD:C_0603_1608Metric
C10 | 10n | MORI_Custom:C_0603_1608Metric__P5_C10
C11 | 10n | MORI_Custom:C_0603_1608Metric__P5_C11
C12 | 100n | Capacitor_SMD:C_0603_1608Metric
H1 | M2 clearance | MountingHole:MountingHole_2.2mm_M2
H2 | M2 clearance | MountingHole:MountingHole_2.2mm_M2
H3 | M2 clearance | MountingHole:MountingHole_2.2mm_M2
H4 | M2 clearance | MountingHole:MountingHole_2.2mm_M2

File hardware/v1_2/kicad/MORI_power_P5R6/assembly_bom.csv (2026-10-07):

ref | value | footprint | source | note
J1 | PACK AFTER 6.3A FUSE | MORI_Custom:AMASS_XT30UPB-M_1x02_P5.0mm_Vertical__P3_J1 |  | Protected finished3S pack through external6.3A fuse. On-board Q90 is controlled by rear SW1. No direct small-switch load current.
J2 | WHEEL BUCK VIN | MORI_Custom:AMASS_XT30UPB-M_1x02_P5.0mm_Vertical__P3_J2__P5_J2 |  | AMASS XT30UPB-M PCB: pin1 minus, pin2 plus; mating housing polarization plus continuity check mandatory.
J3 | WHEEL BUCK 9V RETURN | MORI_Custom:AMASS_XT30UPB-M_1x02_P5.0mm_Vertical__P3R1_J3 |  | AMASS XT30UPB-M PCB: pin1 minus, pin2 plus; mating housing polarization plus continuity check mandatory.
J4 | HEAD BUCK VIN | MORI_Custom:AMASS_XT30UPB-M_1x02_P5.0mm_Vertical__P2_J4__P3_J4__P3R1_J4 |  | AMASS XT30UPB-M PCB: pin1 minus, pin2 plus; mating housing polarization plus continuity check mandatory.
J5 | HEAD BUCK 6V RETURN | MORI_Custom:AMASS_XT30UPB-M_1x02_P5.0mm_Vertical__P2_J5__P3_J5__P5_J5 |  | AMASS XT30UPB-M PCB: pin1 minus, pin2 plus; mating housing polarization plus continuity check mandatory.
J6 | BAT_MON SERVICE / DNP | MORI_Custom:AMASS_XT30UPB-M_1x02_P5.0mm_Vertical__P3_J6__P3R1_J6 |  | Legacy external5V feed no longer used. Not5V. Leave unpopulated in S3.
J11 | WHEEL DUMP 5R6 EXTERNAL | MORI_Custom:AMASS_XT30UPB-M_1x02_P5.0mm_Vertical__P5R5_DUMP |  | AMASS XT30UPB-M PCB: pin1 minus, pin2 plus; mating housing polarization plus continuity check mandatory.
J12 | HEAD DUMP 10R EXTERNAL | MORI_Custom:AMASS_XT30UPB-M_1x02_P5.0mm_Vertical__P2_J12__P5_J12__P5R5_DUMP |  | AMASS XT30UPB-M PCB: pin1 minus, pin2 plus; mating housing polarization plus continuity check mandatory.
J7 | S288 L | MORI_Custom:JST_XH_B3B-XH-A_1x03_P2.50mm_Vertical__P2_J7__P3_J7__P5_J7 |  | Board-side XH 3-pin interface only. SCS original 5264-3P uses 1GND/2VCC/3TTL. S288 factory mating plug remains unverified; adapter harness must be confirmed.
J8 | S288 R | MORI_Custom:JST_XH_B3B-XH-A_1x03_P2.50mm_Vertical__P2_J8__P5_J8 |  | Board-side XH 3-pin interface only. SCS original 5264-3P uses 1GND/2VCC/3TTL. S288 factory mating plug remains unverified; adapter harness must be confirmed.
J9 | SCS0009 CHAIN | MORI_Custom:JST_XH_B3B-XH-A_1x03_P2.50mm_Vertical__P5_J9 |  | Board-side XH 3-pin interface only. SCS original 5264-3P uses 1GND/2VCC/3TTL. S288 factory mating plug remains unverified; adapter harness must be confirmed.
J10 | MOTION CONTROL | MORI_Custom:JST_PH_B8B-PH-K_1x08_P2.00mm_Vertical__P4_PH_ANNULUS__P5_J10 | https://www.jst-mfg.com/product/pdf/eng/ePH.pdf | P4 PH 2.0 mm. PHR-8 / SPH-002T-P0.5S. Signal pin numbering unchanged. Check both mating views; never wire by color alone.
J13 | S288 DATA | MORI_Custom:JST_PH_B2B-PH-K_1x02_P2.00mm_Vertical__P4_PH_ANNULUS | https://www.jst-mfg.com/product/pdf/eng/ePH.pdf | P4 PH 2.0 mm. PHR-2 / SPH-002T-P0.5S. Signal pin numbering unchanged. Check both mating views; never wire by color alone.
J14 | HEAD DATA | MORI_Custom:JST_PH_B3B-PH-K_1x03_P2.00mm_Vertical__P4_PH_ANNULUS | https://www.jst-mfg.com/product/pdf/eng/ePH.pdf | P4 PH 2.0 mm. PHR-3 / SPH-002T-P0.5S. Signal pin numbering unchanged. Check both mating views; never wire by color alone.
J15 | CHARGE INTERLOCK | MORI_Custom:JST_PH_B2B-PH-K_1x02_P2.00mm_Vertical__P4_PH_ANNULUS__P3R1_J15 | https://www.jst-mfg.com/product/pdf/eng/ePH.pdf | P4 PH 2.0 mm. PHR-2 / SPH-002T-P0.5S. Signal pin numbering unchanged. Check both mating views; never wire by color alone.
J16 | CHARGER RAW VBUS SENSE | MORI_Custom:JST_PH_B2B-PH-K_1x02_P2.00mm_Vertical__P4_PH_ANNULUS__P3R1_J16 | https://www.jst-mfg.com/product/pdf/eng/ePH.pdf | P4 PH 2.0 mm. PHR-2 / SPH-002T-P0.5S. Signal pin numbering unchanged. Check both mating views; never wire by color alone.
Q1 | AO4407A | MORI_Custom:SOIC-8_3.9x4.9mm_P1.27mm__P5_Q1 | https://www.aosmd.com/sites/default/files/res/datasheets/AO4407A.pdf
R1 | 10k | Resistor_SMD:R_0603_1608Metric
D1 | BZT52H-C10,115 | Diode_SMD:D_SOD-123F
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

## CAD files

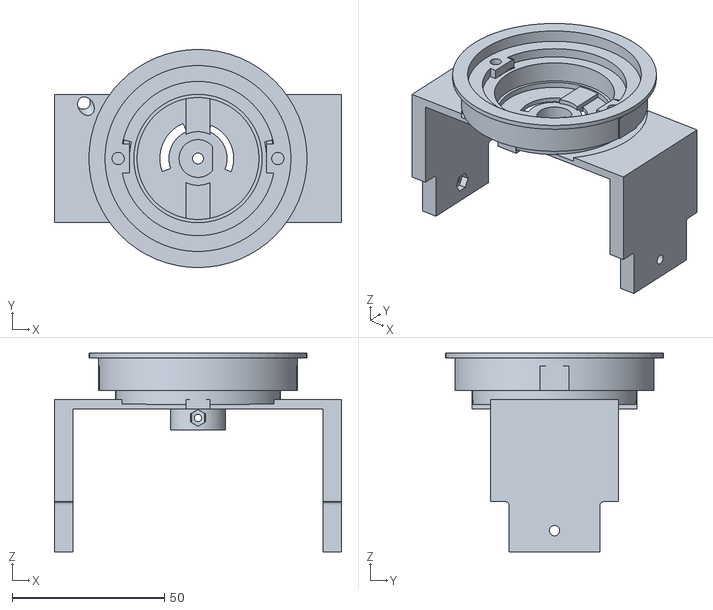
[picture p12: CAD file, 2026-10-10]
mechanical/exports/stl/Yaw_Base.stl
94.2 x 71.6 x 65.3

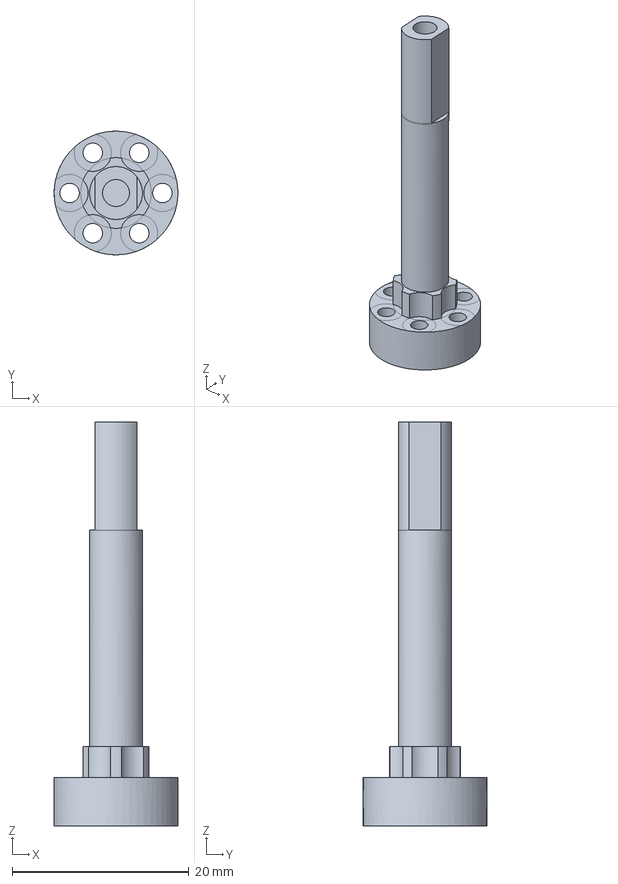
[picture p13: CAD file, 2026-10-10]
mechanical/metal_design/Wheel_Axle_Common_DESIGN_REFERENCE.step
14.0 x 14.0 x 45.7 mm

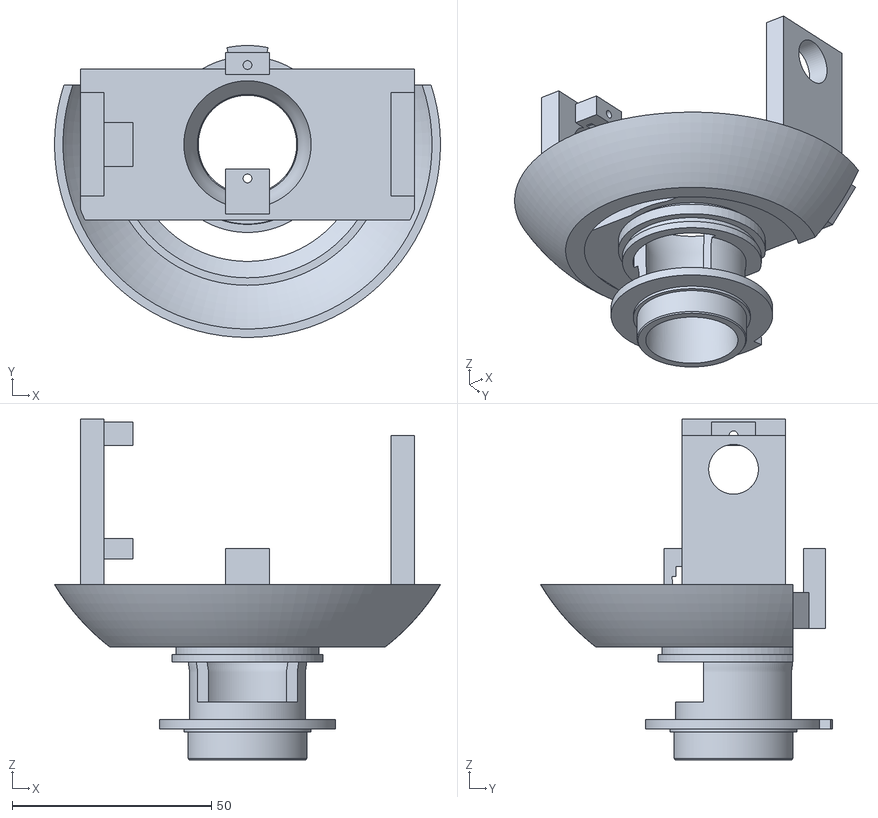
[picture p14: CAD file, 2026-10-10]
mechanical/exports/stl/Pitch_Yoke.stl
97.0 x 73.3 x 85.6

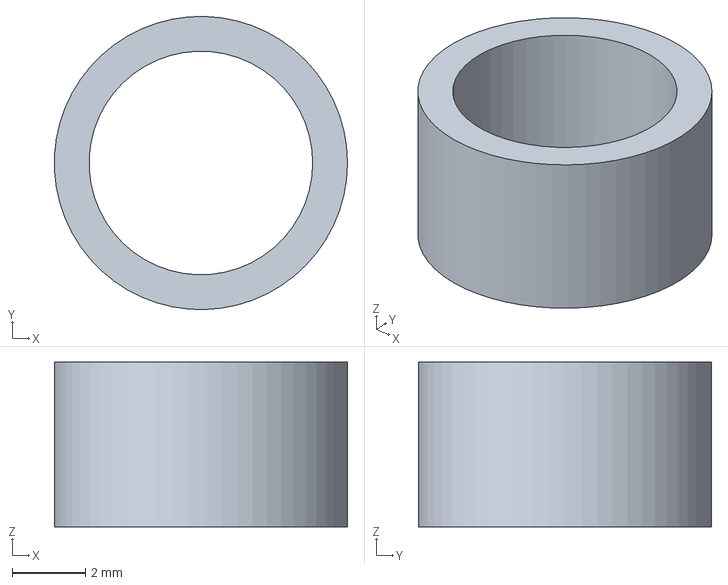
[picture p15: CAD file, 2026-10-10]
mechanical/metal_design/Wheel_Spacer_4.5mm_DESIGN_REFERENCE.step
7.99 x 8.00 x 4.50 mm

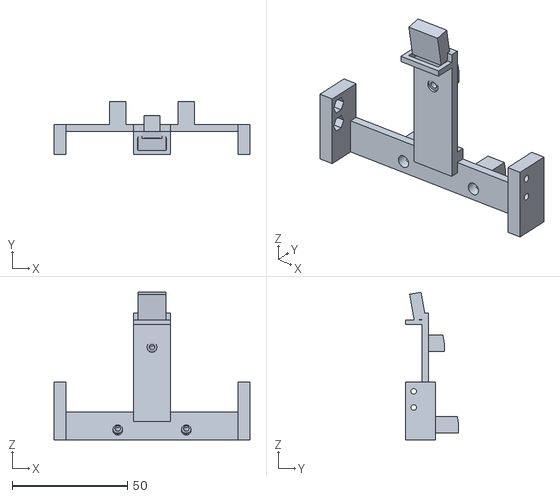
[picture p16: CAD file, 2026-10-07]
mechanical/exports/stl/Display_Frame.stl
85.0 x 23.2 x 64.0

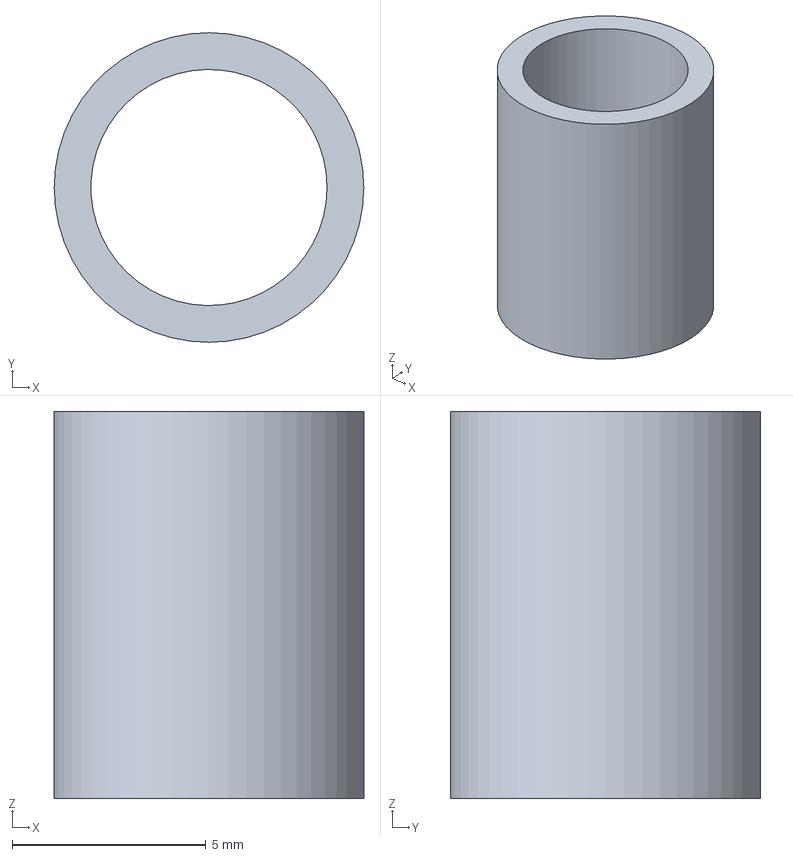
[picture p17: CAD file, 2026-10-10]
mechanical/metal_design/Wheel_Spacer_10mm_DESIGN_REFERENCE.step
8.00 x 8.00 x 10.0 mm

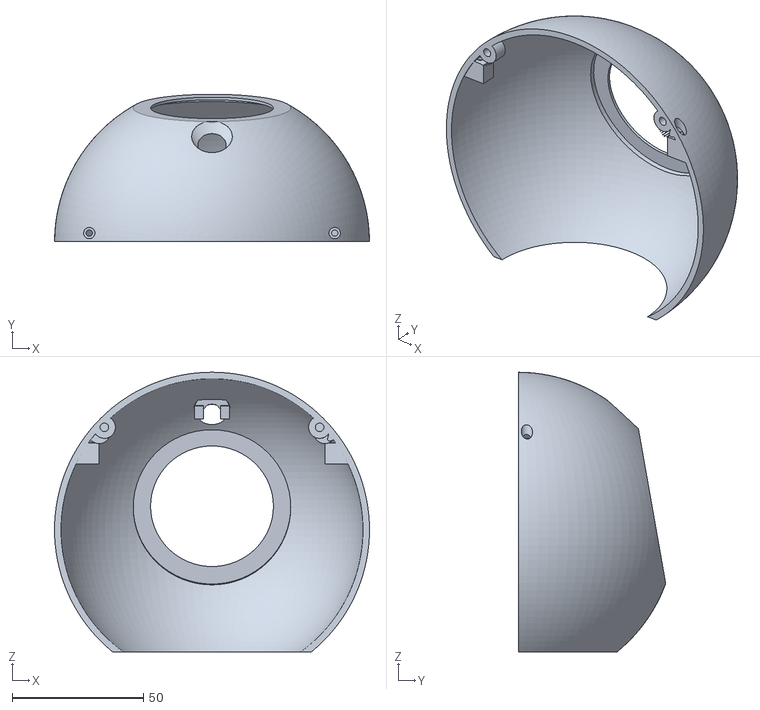
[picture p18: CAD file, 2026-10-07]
mechanical/exports/stl/Head_Front.stl
120.0 x 56.2 x 106.5

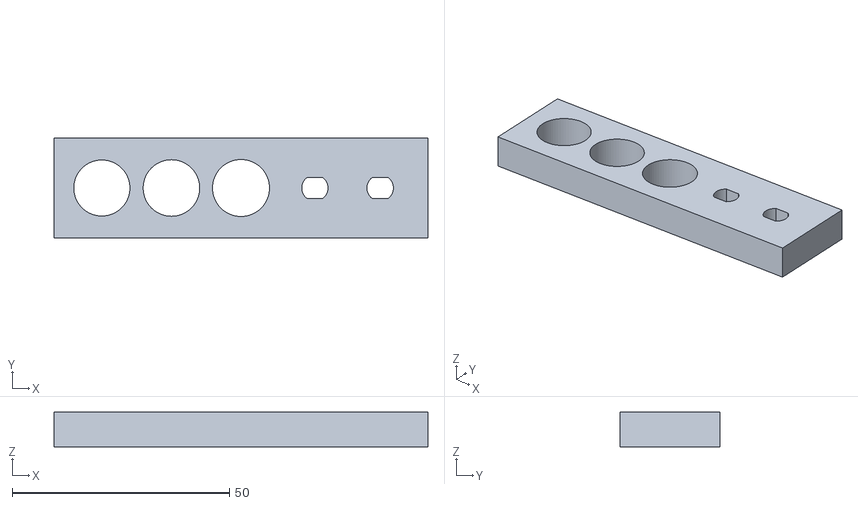
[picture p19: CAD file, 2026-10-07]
mechanical/exports/stl/Coupon_Wheel_Fit.stl
86.0 x 23.0 x 8.00

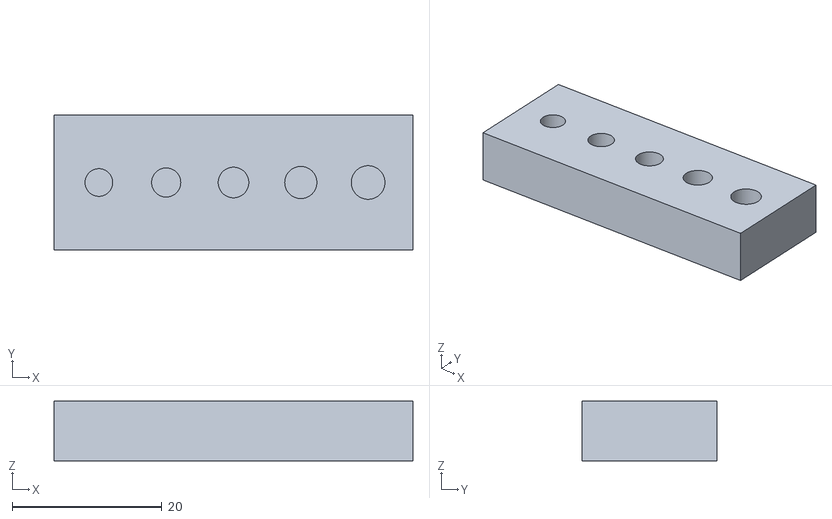
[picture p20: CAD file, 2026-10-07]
mechanical/exports/stl/Coupon_Insert.stl
48.0 x 18.0 x 8.00

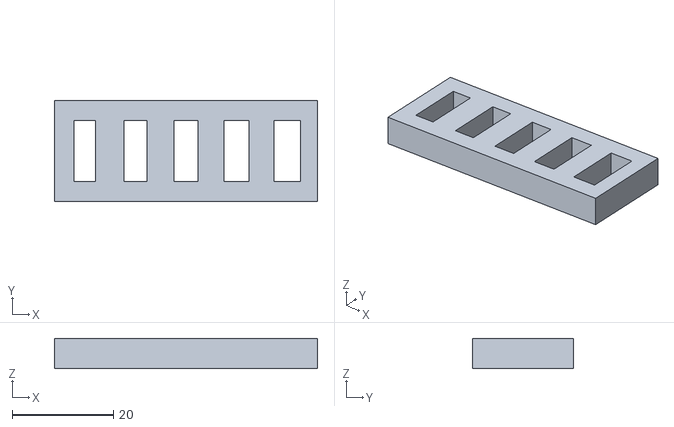
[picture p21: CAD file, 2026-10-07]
mechanical/exports/stl/Coupon_Plane_Fit.stl
52.0 x 20.0 x 6.00

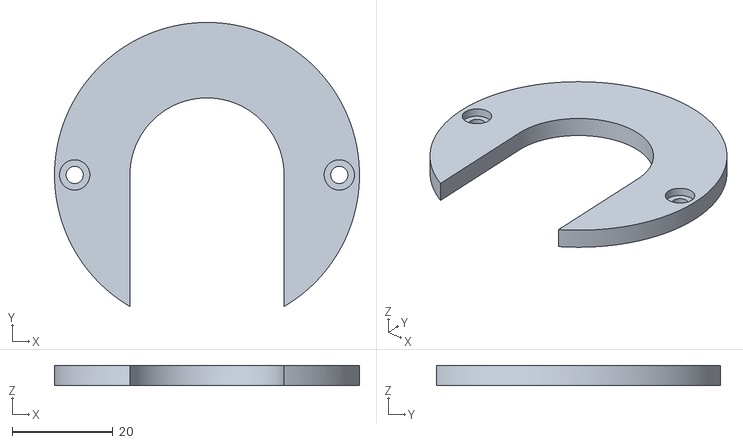
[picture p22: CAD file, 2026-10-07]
mechanical/exports/stl/Yaw_Anti_Lift_Keeper.stl
60.4 x 56.3 x 4.00

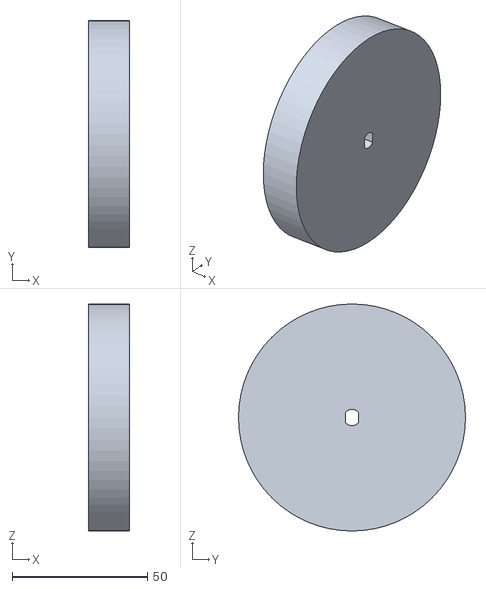
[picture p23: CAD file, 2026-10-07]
mechanical/exports/stl/Wheel_Hub_L.stl
15.0 x 84.0 x 84.0

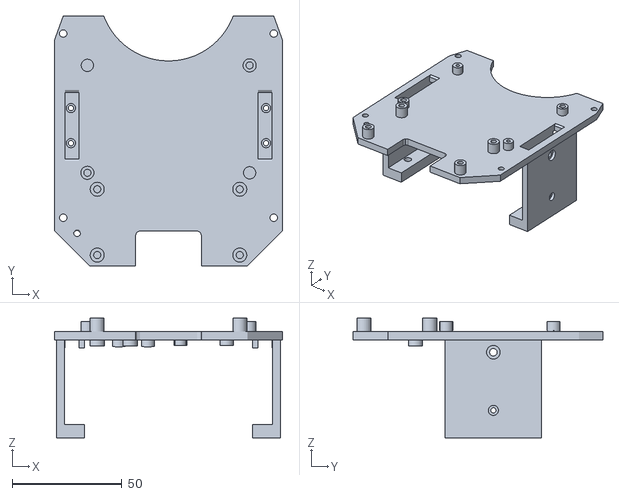
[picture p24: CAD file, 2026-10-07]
mechanical/exports/stl/Load_Frame.stl
104.0 x 114.0 x 54.5

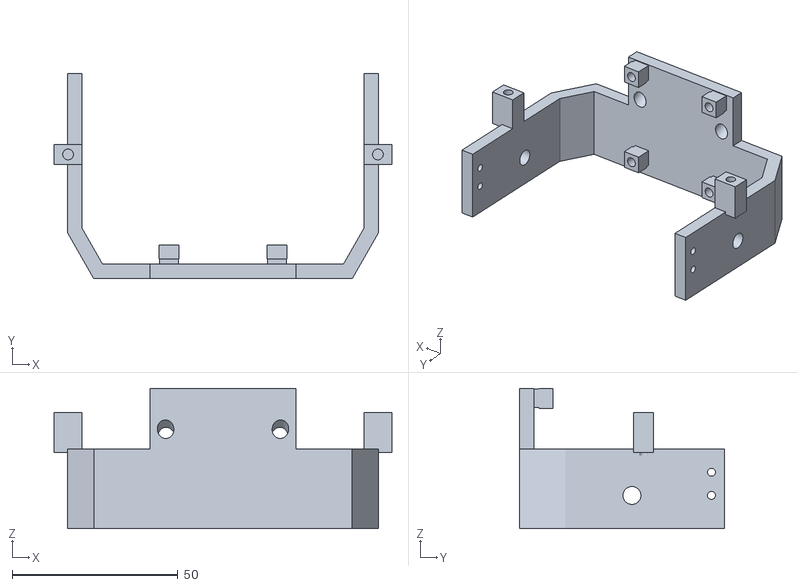
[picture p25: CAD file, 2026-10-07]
mechanical/exports/stl/Pitch_Cradle.stl
102.0 x 62.0 x 42.3

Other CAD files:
mechanical/exports/stl/Parking_Cradle.stl
mechanical/exports/stl/Body_Rear.stl
mechanical/exports/stl/Coupon_Mating_Tab.stl
mechanical/exports/stl/Body_Front.stl
mechanical/exports/stl/Battery_Tray.stl
mechanical/exports/stl/Drive_Bridge.stl
mechanical/exports/stl/Head_Rear.stl
mechanical/exports/stl/Motor_Retainer.stl
mechanical/exports/stl/Wheel_Hub_R.stl
mechanical/exports/stl/Yaw_Reaction_Link.stl
mechanical/mori_assembly_animation.blend
mechanical/mori_electronics_detail.blend
mechanical/mori_v1_2.blend

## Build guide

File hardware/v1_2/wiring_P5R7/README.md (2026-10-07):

# P5R7 端口与接线增补

**E 插合待核：**正确针号/方向保持，但直针与 WeAct 成品孔的兼容性尚未确认；[增补 A1](https://github.com/deanxizian/MORI/blob/48fe22aa75554c9d7bb237e2d2dcacca7f83dde1/hardware/v1_2/reviews/weact_E_J3_20260930/E_pin_hole_addendum_20261001/README.md)。不得强压、扩孔或缩针。

当前组合：motion P5R7、rear P5R7、power P5R6、IMU P5R4。各编号对应的信号、MCU GPIO 和线束对端保持；实物均 NOT_TESTED。

**本目录是端口定义，不是线束加工图。** `04_线束汇总.csv` 中的成品长度、剪线公差、分支基准和运动服务环尚未定型，统一标为 NOT_TESTED / BLOCKED，禁止据此裁线或生产。现有电气连通定义不等于线束机械设计完成。最终长度需以批准的整机路径、接插件端面及余量复核后单独交接。

- 运动板 WeAct 元件面朝上，所有排针从背面向下；E 孔阵列 X+2.54 mm，只有 E7/NRST 接入载板。E 向下后，原来的顶部弯针维护方式不能直接沿用；SWD 可接触性由机械复核。
- 后板 J3 在 B 面，180°，原生1号孔 (14.45,21.20) mm；顶视图从左到右4、3、2、1。1=MASTER_RETURN、2=GND、3=LOOP_3V3、4=CLR_N。
- 当前 CSV 已同步板号、J3 面向和坐标；P5R6 工作簿保留作历史记录，不作为本次装配方向依据。

原生几何、逐针数据及未闭合事项见 [交接记录](https://github.com/deanxizian/MORI/blob/48fe22aa75554c9d7bb237e2d2dcacca7f83dde1/hardware/v1_2/reviews/weact_E_J3_20260930/README.md)。原理图保留的 SW1 与整机已取消的外露开关存在单独的功能交接事项；本次局部插合修正不表示物理断电/急停已闭合。

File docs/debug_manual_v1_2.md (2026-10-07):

# V1.2 调试与故障说明

当前仅主机/模拟可执行；下表所有上电、旋转、热、平衡和续航项均 NOT_TESTED。STM32镜像仍禁驱，物理端口/按钮/功率安全链未释放。不要将旧ESP32刷写命令、GPIO、PWM脉宽/增益、2S阈值用于1.2。

网页 `STOP_MOTION`：取消主动位移/巡游/跟随，健康时继续平衡。失联/300ms租约到期同义；失去互联网不保持最后非零目标。`DISARM`需可靠支撑，`FAULT_STOP`/硬件禁驱可能使机器人倒下。低电量是提前支撑请求；无法保证自行站稳、回托架或自动回充。故障不自动重启上力。视觉sleep仅闭眼。

## 可离线执行

按根目录README启动 → 用一次性码绑定SIMULATED → 取得控制权 → 明确解锁模拟 → 前进100mm → 停止 → 在视觉页选择目标并模拟跟随 → 触发多人/丢失检查停止 → 维护页模拟严重故障 → 确认支撑并人工清故障，再次显式解锁才允许模拟运动。没有实物地址或API主密钥参与。

`bash tools/test-motion-v1_2.sh` 检查S288坏帧/位翻转/截断/符号/齿比/回绕/超时、SCS大端/错误/映射、IMU旋转与SI、租约、STOP/禁驱/故障锁存、输入NaN、持续饱和和控制超时。`bash tools/test-s288-reference.sh`是官方C对照的合成报文，不能称为实机golden vectors。离线S288回放见README，输出保留capture_monotonic_us；不同主控的时间不能直接相减。

## 实物递进记录（各级未授权/未满足前置条件不得执行）

| 级别 | 前置条件 | 命令/操作 | 观测量与通过阈值 | 停止条件 | 当前 |
|---|---|---|---|---|---|
| 0 断电 | 硬件签字的线序/实物版本/电源与极性；外部支撑 | 文档核对、断电导通/绝缘；无运动命令 | 四执行器、独立轮承载路径；3S不接CAM BAT；FFC接触面一致；电源额定按硬件记录 | 任何未知针脚、电平/极性冲突 | NOT_TESTED |
| 1 限流且禁驱 | 托架、物理急停、额定限流电源；限流值由硬件设定 | 仅状态读取；不发ARM/位置/速度/力矩 | 复位/下载/掉电输出禁止；3S/6V/5V各支路在签字容差内；无倒灌 | 支路越限、发热、异味、意外使能 | NOT_TESTED |
| 2 单模块 | 每次只接一个模块，执行器功率禁止 | ICM WHO=0x47/六面静态/手动倾斜；相机屏音频分别测试；S288单ID只读探测由合格PHY发送 | 原始数据/轴向/帧时间正确；位错误、重复ID=0；记录示波器6Mbps实际误差；不把协议估计扭矩作负载力矩 | 电平不符/CRC错误/时戳异常/排线升温 | NOT_TESTED |
| 3 悬空单轮 | 轮保护罩、限流、已签字停止与禁驱行为；候选低出力参数经台架批准 | 显式本地解锁一次有界试验；V1.2指令适配器尚BLOCKED，不提供可误发的裸包 | 极低已批准torque/speed，固定期限；方向/反馈/齿比一次换算；电流/电压/温度记录 | 非预期旋转、通信超时、任一限制触发 | NOT_TESTED |
| 4 双轮/回灌/急停 | 单轮通过、实际回灌钳位/保护/仪器及外部支撑 | 重复有界启停、断通信、按物理急停、复位；分别核mode0/零扭矩/KpKd0/timeout | 任何尖峰不能越执行器上限；左右年龄/偏差和禁驱延迟符合签字预算；无自动重启 | 保护不动作、钳位过热、负压/过压、未知锁定行为 | NOT_TESTED |
| 5 台架辨识 | 真实轮径/质量/重心/头姿/轴符号与时钟已测 | 有界激励，离线拟合驱动、齿隙、时延与参数；不逐帧LLM | 拟合误差、裕量、增益来源/版本；负载温升和总线年龄有实测最大值 | 发散、持续饱和、限流/热保护接近 | NOT_TESTED |
| 6 防摔保护平衡 | 安全链通过、参数评审、吊绳/保护框和人工看护 | 近直立显式ARM，STOP撤销目标，受控轻扰动；不从倒地自动起身 | 姿态、轮输出、恢复时间、最大时延/饱和均满足签字指标 | 倾角或电源/反馈失效即禁驱，允许由保护承接 | NOT_TESTED |
| 7 清场低速 | 第6级通过，无楼梯/门槛/人群；人体能立即物理禁驱 | 先手动≤0.10m/s/单段≤0.30m，再头跟踪，再跟随/有限巡游；逐项解锁 | 300ms租约、250ms观测起点；遮挡/多人/头反馈失效停止；测轮滑/漂移 | 目标不确定、观察过期、场地不再清空、网络故障 | NOT_TESTED |
| 8 60分钟混合工况 | 各模式/热/电池验证通过，满电和充电方式已核 | 真实连续60min平衡+双眼+跟踪；累计移动≥10min、语音≥10min、每分钟小头动 | 真实电流/电压/温度/累计能量/最差时延；不使用仿真时钟顶替续航 | 低电支撑请求、保护触发、热/时延越限 | NOT_TESTED |

## 方向、反馈与参数

M=(右,前,上)，C=(M.Y,-M.X,M.Z)。身体正前倾=机械−X/控制+y；头抬脸=机械+X/控制−y。先验证六面和手动前倾，记录IMU安装矩阵；电机正输出应使各轮接地点向前推动车身，左右镜像分别确认，不复制符号。轮前进用于追赶向前倾倒的质心，姿态PD公共输出应对正前倾给正向纠偏；速度环通过倾角参考调节，初始可能先反向让机身倾斜，不能据单一瞬间误判。

S288 rotor累计角与13bit输出绝对角单列。丢帧间隔过大或跳变时累计位置无效，不自动接续猜圈数。SCS位置是原始计数，标定后才能称yaw/pitch实测角；raw速度/负载单位未核不转换成Nm。联合region缺失时真实头目标拒绝。抬头重力负载下不默认松扭矩。

新3S保护阈值目前null。调参文件不得从夹具复制physical_verified=true，不得以删安全门通过测试。功能按钮普通短按会话、双击停止；维护长按需要支撑确认与维护状态，不能把内部BOOT算成已安装外部用户按钮。

## 故障定位

| 反馈 | 解释 / 恢复 |
|---|---|
| REJECTED / PHYSICAL_GATES_NOT_VERIFIED | 真实能力未释放；保持模拟，不能通过改网页布尔绕过 |
| EXPIRED / NO_LEASE / CONTROL_OWNED | 数据陈旧/无控制权/另一客户端占用；先读新状态再显式取得控制权，不重发旧动作 |
| IMU / WHEEL / SEVERE_TILT / POWER / CONTROL_TIMEOUT / SATURATION | 严重故障锁存；先可靠支撑，排查物理原因，再人工ACK和重新检查；不会自动ARM |
| 目标/头反馈丢失 | 取消跟随并归零位移；检查采集ID/年龄/头角/置信度后重新确认目标 |
| 未提供唤醒模型/云密钥 | 用按钮/网页mock开发；不把字符串设置称为模型完成 |

## 每次实验记录模板

```text
run_id/date/operator:
evidence_level: BENCH | ROBOT
result: PASS | FAIL | NOT_TESTED | BLOCKED | NOT_APPLICABLE
hardware_revision/serials/PCB/FFC/cabling:
spec/electrical/mechanical revision + hashes:
firmware ELF/bin/parameters hashes + toolchain:
support confirmation and physical inhibit evidence:
command_id/session/source/command/limits/deadline:
clock source / DRDY / frame ID / original capture timestamp:
voltage min/max incl regeneration, signed current, temperatures:
IMU/wheel/head validity + age/skew; compute and full-frame max/p50/p95/p99:
CRC/timeout/retry/log-drop counts:
observed motion/thermal/duration; instrument/video/raw log paths:
stop reason/fault/ACK/re-arm chronology:
reviewer / allowed next step / unresolved risks:
```

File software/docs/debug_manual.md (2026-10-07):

# MORI分阶段调试手册（HW-SW-0.4 / SW-0.4）

已按用户指令合并0.4软件接口，GPIO/安全门/保护阈值不变。上电前逐项核验本手册及hw_sw_0_4.md；接口测试通过不能代替下列实物前置检查。

当前全部实物步骤为 **NOT_TESTED**。这是模块台架候选，非冻结装机BOM。轮子由1:1候选皮带连接独立6 mm轮轴，电机不承载轮子；有效半径、齿数、传动弹性/摩擦/齿隙、整机质量和重心都未辨识。只有两轮主动平衡，断电/急停/严重故障会倒下；不承诺断电站立、自起或回充。支撑托架仅用于测试保护，不是运行时第三接地点。

先将用户明确提供的、已经识别的本地端口填入`MORI_PORT`；本文命令不会自动运行。当前交付没有连接设备或烧录。需要烧录时另行核对端口、板卡v1.1、供电隔离和镜像SHA，不使用`reports/compile_only/DO_NOT_FLASH_gated_coverage/`中的任何镜像。

通用记录模板在`config/hardware_test_record.template.json`。每步复制一份，填写实际命令、版本/哈希、UTC、操作者、仪器/校准、实测值与最大值、原始记录链接、停止原因和签字；没有数据保持NOT_TESTED，失败填FAIL。每一阶段都必须有上一阶段PASS证据，不能用主机测试替代。

## 0. 断电检查 — NOT_TESTED

**前置**：电池/USB/舵机支路全部隔离；机械支撑已准备，电机/头线束与轮轴可独立检查。阅读根AGENTS、params及尺寸表，确认开发板和IMU当前需外置台架，不能缩放实物硬塞。

**命令**（只操作本机文件）：

```sh
bash software/scripts/test_host.sh
python3 -m unittest discover -s software/tests -p 'test_*.py' -v
python3 software/scripts/verify_delivery.py --require-current-handoff
```

**观测/阈值**：恰好2轮电机+1位置舵机；pinmap快照逐线对照board.h；19/20及43/44保留，无35–37/启动脚误用。nSLEEP拆上拉并有硬件下拉，0.39Ω改装、外部看门狗、物理急停逻辑及回灌钳位须由硬件任务提供可检查记录。保险、BMS、匹配充电器/电池及电源反接防护未定则禁止进入出力阶段。电气连通/绝缘阈值由硬件原理图与器件规格签字后填写，软件不能编造阻值合格线。

J4/J5为自定义XH6：1绿GND、2白B原始5V、3黄A原始5V、4蓝DEVKIT_5V、5黑M2、6红M1，不是原厂排母线序；必须看针号/通断而非颜色。四条A/B先经3.3V供电的SN74LVC14AD（输入容忍5.5V）；禁止5V直入ESP32。控制left接模型R（X正），right接模型L。

**停止**：任一接线不符、装配干涉、轮壳/轮胎间隙不足、线束接触传动、缺失电源安全链。记录逐脚通断与真实照片；不改机械坐标或GPIO来凑测试。

## 1. 限流供电且电机禁用 — NOT_TESTED

**前置**：轮子悬空/机身有托架，头传动断开；功率级与平衡/头/轴四个编译门全关闭。硬件负责人先确定限流值与供电路径，确认试验电源是否可吸收回灌；未经确认不接电机母线。

USB前拔**整个J12逻辑降压模块线束，J14保持连接**，由USB经DevKit 5V/J14供编码器；USB逻辑与外部5V互斥，独立电池仅按已核验路径供电机/头。USB模式禁止Wi-Fi，逻辑含编码器电流预算<500mA，实际USB与线缆能力未测。通电后测原始A/B高电平约5V、转换后约3.3V及低电平/边沿，签字阈值以器件逻辑电平规格为准；超过MCU额定或转换器漏装立即停止。

**命令**：

```sh
python3 software/tools/mori_cli.py capture --port "$MORI_PORT" --seconds 60 --output software/reports/DEVICE_disabled.csv
python3 software/tools/mori_cli.py send --port "$MORI_PORT" --output software/reports/DEVICE_info.csv --command info --command status
```

**观测/阈值**：INFO固件SHA、IDF v5.5.2、安全门=0；ARM低、四桥输入低、头PWM无脉冲。示波器覆盖上电、复位及已授权下载过程；GPIO38为v1.1 RGB，不用GPIO48 RGB旧板。确认整段都没有非预期使能脉冲。配置8MB Flash，PSRAM目前未启用，不能据INFO断言物理板卡容量/版本已通过。

**停止**：ARM/桥/头有非预期脉冲、电源限流、异常升温或实际端口/板卡不符。记录电压、电流、波形时间范围及最大脉冲宽度（没有脉冲须保存仪器证据），然后隔离供电排查。

## 2. 单模块读数与独立舵机核验 — NOT_TESTED

**前置**：轮驱动持续禁用；I2C由控制任务独占；分别接IMU、INA、电池分压、两NTC和手转编码器。仅断电时改接线。初次头中心用独立受控舵机测试源，拆传动，记录真实中心/方向/范围后才签字开启head门。

**命令**：

```sh
python3 software/tools/mori_cli.py capture --port "$MORI_PORT" --seconds 60 --output software/reports/DEVICE_modules.csv
python3 software/tools/mori_cli.py send --port "$MORI_PORT" --output software/reports/DEVICE_calibrate.csv --command calibrate
python3 software/tools/check_mount.py software/reports/实际测量记录.json
```

**观测/阈值**：IMU地址0x6A/ID0x6C/416Hz/±2g/±500°/s配置、原始与旋转后数据；六面和前倾按direction_checks.md执行。1024个健康静止不同样本才能READY：|gyro|<0.08rad/s、|加速度模长−g|<0.35m/s²、|pitch|<3°、两轮速度<0.01m/s，偏置方差≤0.0001(rad/s)²。在轮功率禁用但逻辑供电有效时手转每个轮子，按同一起止标记累积10圈，候选期望9796.16个边沿（整数计数有边界量化），1:1齿数、有效周长及允许测量误差须记录；48 CPR已含x4，不能再乘4。

比较ADC的VMAIN电压与同节点校准万用表读数；该节点可能与VM_MOTOR隔离，不能用它声称检测所有回灌尖峰。INA有符号母线电流与参考表，不能当每绕组电流。NTC用已知电阻和温度参考校准；开短路模拟应在断电改线并确认电气安全后做。原始ADC≤9或≥4081无效；NTC分压<0.08或>3.05V无效，软件温区0–65°C。测量误差合格线须由硬件/标定记录确定，当前未填。测不到有效值、传感器轴不符、计数跳变都停止，不解锁。

头验证门通过后才发`head 0`，再`head 10`和`head -10`逐步核验；上限±50°不是可直接尝试的实测结论。有效脉宽、供电瞬态、线缆阻力和输出中心误差逐项记录；不使用FS90或连续旋转舵机代替SER0037候选。

## 3. 悬空单电机低占空 — NOT_TESTED

**前置**：上一阶段PASS；拆nSLEEP上拉/下拉、电流限制、外部心跳超时、急停/钳位等功率级检查已签字，才允许本地设置POWER_STAGE_VERIFIED；ENABLE_BALANCE仍n。轮子悬空、工具/线束远离皮带，机身保持校准姿态。方向未确认不启平衡。

**命令**（先校准并等READY，然后显式连续发送）：

```sh
python3 software/tools/mori_cli.py send --port "$MORI_PORT" --output software/reports/DEVICE_L_pulse.csv --command 'arm bench' --command 'duty 0.03 0'
python3 software/tools/mori_cli.py send --port "$MORI_PORT" --output software/reports/DEVICE_R_pulse.csv --command 'arm bench' --command 'duty 0 0.03'
```

每条arm是一次独立人工授权；不要写循环重复脉冲。需要反向时另行明确输入−0.03。3%是低占空探索命令，不保证能克服摩擦；不动不能据此宣称电机失效，也不能盲目加大。上限12%，固定授权200ms，软件提前8ms截止，duty/重复arm不续期。

**观测/阈值**：示波器真实出力≤200ms且占空≤12%；只有指定侧旋转；逻辑正输出、原始编码器计数和控制速度一致。帧计算最大≤1800us、无IMU遗漏。软件保护起点|母线电流|≤1.30A、电机NTC≤65°C，实际硬件签字上限若更严则从严。保持车体倾角<20°，异常时物理急停并接住/托住。

**停止**：方向不符、相电流/母线电流无法解释、超时、nFAULT、卡齿/摩擦/跳齿、限流/温升过快。原始观测标FAIL，禁止confirm_signs硬写通过。没有测每绕组电流时，不可宣称0.39Ω改装效果或热安全通过。

## 4. 双电机、回灌、急停与看门狗 — NOT_TESTED

**前置**：左右单轮方向PASS，功率级仍有真实支撑与可吸收/钳制回灌的路径；BMS/保险/充电安全不能靠软件替代。硬件工程师定义允许的总线峰值/钳位和关断响应。

**命令**：

```sh
python3 software/tools/mori_cli.py send --port "$MORI_PORT" --output software/reports/DEVICE_dual_pulse.csv --command 'arm bench' --command 'duty 0.03 0.03'
```

在受控低能量条件下逐项试物理急停、nFAULT、控制任务停止/复位/失去DRDY、USB拔插；每次独立记录。急停必须直接切硬件安全链，不能只发送串口命令。软件故障恢复需要明确`ack`，随后重新calibrate；ack不再出力。

**观测/阈值**：GPIO42只随健康完成帧翻转；停止控制帧就停止喂狗；ARM不绕过链路，所有复位/故障禁用。记录实际nSLEEP/轮输入关断最大延迟、母线回灌峰值、signed INA电流和仪器带宽。软件检测VMAIN>8.65V故障，但不能覆盖被隔离的VM_MOTOR尖峰。分别在VMAIN和VM_MOTOR同步示波器捕获；回灌钳位R14=25.5kΩ0.1%、R15=10kΩ0.1%、R16=2.2MΩ1%，估算开启8.73–9.04V，必须实测开启、迟滞、峰值和能量/热响应。软件阈值不是硬件峰值许可；硬件更严的绝对额定/钳位值须先填入记录。8ms IMU年龄也不是正常延迟合格线。

**停止**：任一链路不能切断、出现自动重新出力、母线超过已签字限值、供电无吸收路径或电流/温度越限。所有失效项恢复后都须重新人工解锁；不得增加软件“已确认”常量。

## 5. 台架辨识 — NOT_TESTED

**前置**：功率、关断、计数/输出符号、IMU矩阵PASS；机体有受控防摔/约束，测量仪器齐备。电机#4863、2S、电池/最终质量都仍是候选；约1.0kg仅质量预算，非称重结果。

**命令**：以阶段3的显式低占空短脉冲逐次探索，采集`DEVICE_identification_日期.csv`；必要扩大试验必须另行工程审查、接口变更及风险约束，不能突破本软件台架上限绕过许可。

**观测/阈值**：齿数、实际轮周长/转速/计数、速度—占空—母线电压关系、正反摩擦死区、皮带弹性/齿隙、真实电流（相/母线分别）、扭矩、质量、重心、惯量与热曲线。记录各试验持续时间、初末温度和最大值；没有长时数据不能判稳态/热余量。模型参数置信区间、可用扭矩/安全温升边界及闭环裕量须有人审核，目前没有预填“调好”的增益。

**停止**：保护任一触发、模型残差不能解释、所需输出持续饱和、扭矩/热余量不足。默认增益0保持；不能通过提高电流/倾倒阈值让曲线好看。

## 6. 防摔保护下平衡 — NOT_TESTED

**前置**：前五步PASS，有已审核的质量/惯量/延迟/扭矩数据与初始增益方案。四安全门按实际项目分别核验，其中平衡功能门只为此阶段明确打开；本地操作者可立即触及物理急停。托架/保护绳不得掩盖运行时仅两轮的事实。

**命令顺序**：`calibrate`→观察READY→`confirm_signs`→`gains <经审查kp kd kv ki>`→`arm balance`。不提供未辨识实机增益；尖括号占位不是可发送命令。每一条由操作者显式输入，可先用CLI `validate`检查格式，不能用测试用的任意增益充当调参结果。

**观测/阈值**：起始解锁|pitch|<3°，正常纠偏无粗暴全局斜率；差动仅剩余余量。计算/传输最大≤1800us，无正常缺样/命令溢出，持续饱和>200ms、倾倒>20°、过流/温/压、急停/nFAULT均锁存FAULT并允许倒入保护。观察`stop`后目标归零且本地平衡继续；500ms通信中断只撤销目标。任何输出符号导致倾倒放大立即急停，不现场猜改PID正负。

**停止**：任一保护、不可控振荡、接近防摔边界、机身/头部/线缆干涉、轮胎打滑、延迟异常。接住/放托架后才主动disarm；不能将成功编译或短时托住当自由平衡PASS。

## 7. 安全场地低速运动与逐项负载 — NOT_TESTED

**前置**：受保护平衡有完整真实日志/重复性证据，场地平整无人靠近运动路径，操作者有硬急停与接住/支撑方案；没有手机App/无线急停替代品。

**命令**：先`move 0.02 0`短时目标，再`stop`；测得可控后逐级增加，不自动循环或补发。孤立命令500ms后会自动撤销运动目标；持续指令必须由后续明确设计的操作者控制产生，当前工具不会替人持续刷新。转向输入单位是差动duty，不是rad/s。

**观测/阈值**：记录最大速度/俯仰、任务最大值/分位数、丢弃/遗漏、左右温度、剩余输出余量与停车距离。先无头/无屏/无无线，再分别加入屏幕、已验证头部±10°动作、最后才是使用已核验非USB逻辑供电时经授权的后台无线负载（USB台架模式始终禁Wi-Fi）；单变量比较。头误差/线缆阻力要独立测量，不能凭视觉认为不扰动平衡。

电池<6.8V告警并禁止新解锁/撤销运动目标，<6.6V请求人工支撑，<6.0V严重禁用。提前移入托架，不承诺自行停稳或回充。最终正常运行温度、续航与停止距离目前均NOT_TESTED。

**停止**：低电支撑请求、任何FAULT、场地有人进入、异常滑移/摇摆/头干涉/日志异常。托住后disarm并记录原因，不自动清故障重试。

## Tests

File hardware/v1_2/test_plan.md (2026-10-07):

# P5R7 prototype test prerequisites

Current set: motion/rear **P5R7**, power **P5R6**, IMU **P5R4**. All physical tests remain **NOT_TESTED**; manufacturing and power-on release remain **BLOCKED**. Use the exact [native bundles](native_projects/README.md), current [electrical contract](../../contracts/electrical_interfaces.json) and [P5R7 harness pin table](wiring_P5R7/README.md).

Before the historical test sequence below: verify WeAct component side UP / pins DOWN and the corrected E footprint; verify rear J3 on B.Cu in the P5R7 position; use integrated dual 5V converters on the power PCB. LCD pins 16–18 are documented NC on both boards, but purchased FFC direction, continuity and supply headroom are still unverified. Harness lengths and unresolved endpoints do not constitute supplier fabrication drawings. Retain physical emergency-stop and no automatic re-arm requirements.

The P1/S3/P4 entries below are retained historical planning context, not the current wiring authority. Reconcile each numeric limit and pin against the above board set before use; no test is marked passed by this metadata update.

# P1 上电、台架与整机验证

**S3前置增量**：若装配的是新板载5V原理图，先执行[S3-T01～T06](https://github.com/deanxizian/MORI/blob/48fe22aa75554c9d7bb237e2d2dcacca7f83dde1/hardware/v1_2/schematic_S3/README.md)的断电、空载、假负载、线束瞬态、分支故障和双MCU并发检查，再接续下表的电机/平衡测试。下面T04中的两个外置5V模块已被S3替换；9V/6V模块测试仍保留。S3尚无PCB/实板，全部增量为NOT_TESTED。

版本V1.2-H0.2-P1，2026-09-22。**全部实物记录 NOT_TESTED**。用户已确认：器件均未采购；已有万用表、限流电源。它们足以开展断电检查和部分静态上电，不能验证6Mbps波形、快速回灌峰值、温升或目标时延。未刷写任何机器人。

所有测试先完成对应器件/极性/额定核验；表中数字是初始限制或验收目标，不是通过记录。仪器限流输出不得直接并接锂电池充电，也不能默认能吸收电机制动能量。每步由操作者在现场执行，托架、外部保护随阶段配置，不自动开始电机试验。

| ID | 前置条件与操作 | 设备、观测量 | 通过条件 | 停止条件、风险 | 记录字段 |
|---|---|---|---|---|---|
| T01 断电 | 收到确切版本，核所有BOM/焊接；不接电池。逐针测连接器、极性、相邻脚短路，确认PMOS/电解方向、保险和XH转厂线 | 已有万用表，放大镜；阻值、导通、二极管压降 | 与netlist一致，无未知短路；1000uF充电造成阻值变化需区分 | 任一正负反接、错件、错版、未知针序即停；电池短路风险 | 版本/照片/每根线起止针/阻值/异常 |
| T02 运动逻辑 | 只接运动板J1；外部器件、轮/头和CAM断开。5.0V限流先0.15A，不能为克服故障盲目上调 | 已有电源+万用表；输入电流、3V3、ARM_Q、两PHY OE | 3V3在3.2–3.4V目标，ARM_Q低、OE禁用；不持续触发限流 | 3V3>3.6V、意外ARM、异常电流/发热即断；避免探针短邻脚 | Vin/Ilimit/Iidle/V3V3/ARM/OE |
| T03 电源空载 | 无电池、马达及外部buck；输入9→12.6V分级，先0.05A限流；按图给控制侧3V3 | 已有电源+万用表；反接阻断、分流器、ADC、静态漏电 | ADC缩放与模型/电阻公差一致；反接不向下游供电 | 限流/器件过压/反灌逻辑轨异常停止；反接试验只能小电流、无锂电池 | 极性/Vraw/Vadc/注入电流 |
| T04 单稳压支路 | 使用待核验的实际模块；先无负载，再小功率电阻负载，后动态负载。分别9V/6V/两个5V | 万用表可做静态；示波器、电子负载、温度探头需借用/补齐 | 电压公差/纹波/温升满足实际模块与下游额定；确认掉压/限流/短路恢复 | 超额定、振荡、持续限流、温度超预定上限即停 | 模块版号、输入/输出V/I、效率、波形、温度 |
| T05 锁存与重启 | 轮/头仍断开；用最小板测固件测试上电/NRST/CLR/J8断线/FAULT/CHG；IWDG故意停喂 | 万用表只看静态；示波器记录短暂ARM脉冲 | 任何启动/故障/物理断线均禁驱；解除后无新ARM边沿不能恢复；CAM重启不重置运动 | 任意非预期使能即停；不接负载掩盖启动瞬态 | 每次触发方式、ARM/OE/电源门极波形、复位原因 |
| T06 IMU | T02通过；断电接20×16板，确认刚性安装与芯片到机身变换；读取ID/六轴/时间戳 | 需内部SWD调试器及逻辑分析仪；IRQ周期、SPI错误、FIFO、姿态 | ID与所购手册一致；1kHz候选DRDY连续；SPI6MHz稳定；坐标符号正确 | 数据不更新、轴向错误、时间戳倒退、FIFO溢出停止 | ID/寄存器/原始六轴/采样周期/姿态标定矩阵 |
| T07 屏/相机/音频单项 | 断电测18P线端到端；核16–18保留脚和3.3V供电。先屏，再相机，后音频 | DMM、内部CAM USB调试、日志；必要示波器 | 黑底双眼真实45.68mm有效区；OV3660真实图像；两个麦与播放参考槽可复核；BTL不接地 | 线序/电平不明不插；音频削波、轨压跌落、功放过热即停 | 屏/摄像头ID、排线方向、图像模式、声道顺序、音量/电流 |
| T08 6Mbps物理层 | 厂商确认TTL门槛；先无马达假负载/回环，再一台无转矩请求；硬件禁驱可达 | **≥100MHz示波器、建议≥100MS/s逻辑分析仪**需借用/补齐 | 6Mbps实际波特率、VOH/VIL/过冲/总线释放均在双方数据范围；10万帧无未解释CRC/帧错误仅是阶段目标 | 总线争用/越压/意外转动/解析错位即停 | TX/OE/BUS/RX波形、固件版本、原始字节、各时延P99/max |
| T09 单电机悬空与符号 | T08通过、单只设置ID、可靠固定/悬空；从最小可确认转矩/速度开始，不使用未标定协议值当Nm | 限流电源、DMM、示波器、光学转速参考/砝码力臂 | 输出8192状态/转、左右方向、转子/输出角度和单位一致；失联时行为可解释 | 方向相反、超速、异常齿轮声、反馈过期立即禁驱；禁止长堵转 | ID/序列号/限幅/电压/电流/角度/实际rpm/反馈年龄 |
| T10 双轮调度 | 两轮独立ID已确认；悬空，零位移；注入坏CRC、旧帧、半包、丢包、堵塞 | 逻辑分析仪+固件日志；500Hz候选周期 | 两轮窗口有界，异常不续租、无无限等待；无重复ID；更新周期符合稳定性设计 | 新包假装旧包有效、超期仍维持无界命令即停 | 周期抖动、CRC率、超时计数、最大反馈年龄 |
| T11 回灌/失电 | 先无马达，用受控电流+已资格电阻/电子负载注入两执行器母线；验证比较器、PMOS和吸能后再低能量制动 | 示波器/差分或适当接地探头、功率电阻、温度探头；普通电源不能当吸能负载 | 静态门限在power_integrity范围；动态峰值保守目标轮<12.2V、头<7.3V；无复燃重启，吸能温度受控 | 达到目标边界即停，不把12.6/7.4绝对上限当试验目标；电阻烫伤/跌落风险 | 能量、I/V时间曲线、温升、BMS替代断开时响应 |
| T12 头部两轴及并发 | 已核4.8–6V能力、反馈寄存器/零点、轴承与限位；先脱机构，再小角度加负载 | DMM可测平均保持电流；示波器/温度探头/角度尺 | 定位回差、保持/峰值电流、线缆阻力可复核；与双轮并发无欠压；开机1000uF充电浪涌不致复位/跳闸 | 顶限位、持续堵转、电源跌落/热异常停止；不凭降低PWM容忍过压 | yaw/pitch命令与回读、实角/回差、负载、温度、轨波形 |
| T13 连续能力/平衡台架 | 完成轮摩擦/齿隙/惯量测定；逐级短时负载，限定电流/温升与占空，更新模型后才小角度平衡 | 可调配重、转动惯量/质心测量、可靠外部保护 | 实测连续区域覆盖选用模型，饱和/延迟可解释；不能把支撑反力算为自由平衡 | 预设角度/温度/电流/年龄越界停止；不以触发电机过热保护作为正常试验终点 | 分组质量、COM、惯量范围、地面摩擦、连续区域和控制日志 |
| T14 外部保护整机 | T13通过，清场平硬无阶差、有人看护；初始0.10m/s/0.30m短段 | 外部防摔约束/实体禁驱、相机日志 | 本机保护正常；STOP_MOTION撤位移但健康平衡继续；FAULT/DISARM行为单独记录 | 人员宠物进入、拖线、地面变化、失稳、反馈异常停；无避障认证 | 指令/姿态/电流/失联事件/支撑是否受力 |
| T15 音视频网络压力 | 单外设全过；真实双眼+QVGA跟踪+录播音+Wi-Fi持续运行，CPU/PSRAM故意施压 | 日志+功耗/温度记录 | 报告P95/P99观测年龄；>250ms撤跟随位移；无OOM/音频长期断流/运动重置；达不到就报FAIL | 过龄观察继续发移动、控制周期受影响、掉电/过热即停 | 帧时间/年龄/丢帧、I2S缺块、buffer水位、CPU、内存、W |
| T16 充电资格 | **先有精确成品包和3S模块**，核CC/PD、限流、CV、公差、NTC、均衡、保护、电源路径；托架禁驱 | 电池厂文件+专用电池测试/单节测量/温度与示波器，当前设备不足 | 各单节、总压、电流、温度/终止符合包规格；普通5V行为有界；无掉电反灌 | 任一单节/温度/输入超过厂规即停；不得先接未知锂电池摸索 | 包/模块/适配器版本、CC/PD档、每节V、I/t/T、终止/再充 |
| T17 60分钟 | T01–16相关项完成，电量监测校准；按V1.2混合工况：持续平衡/双眼/跟踪、累计10min移动+10min语音、每分钟一次小头动作 | 能量记录、温度、看护与托架 | ≥60min且无托架承载平衡；完整Wh/最低电压/余量；亮度/音量/模型配置可复现 | 提前低电请求托架；不等BMS突然切断；未达60min如实FAIL | 每秒V/I/W、累计Wh、结束SOC依据、温升、时间、终止原因 |

通用记录头：操作者、日期、器件序列/版本、三板版本与哈希、固件commit、仪器型号/采样率/校准、照片/线束、输入电压/限流、环境温度、原始数据路径、PASS/FAIL/NOT_TESTED及停止原因。不能把串口打印的“成功”当真实硬件证据。

内部测试点复用可接近的连接器/模块排针：运动J1（5V/GND）、U100 C1/C2（3V3/GND）、J8.2（CLR）、J7.2（ARM）、J2/J3（两总线）、U100 P5（SWD/NRST）；电源J1.2/分流器两端/INA输出/J3.2/J5.2/J7.2/J9.2。GH端建议做带保险、编号的测试转接线，禁止用滑动探针短路邻针。示波器地夹不得接BTL负端、PMOS源极或外置电阻pin1。

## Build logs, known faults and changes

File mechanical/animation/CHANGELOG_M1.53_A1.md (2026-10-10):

# V1.2-M1.53-A1

由 M1.53 当前主模型重新生成工程、22 张步骤图及完整 MP4。固定偏航桥左侧既有穿线口向外加宽 0.8 mm；不改变装配步骤、零件数量或硬件位置。

新视频由临时输出路径完成渲染后替换旧文件，并从编码文件回读分辨率、帧数和帧率；工程逐件核对原生网格与终态变换，抽查身体分壳、承重桥和防脱安装路径。完整线束、反力夹初装、人手操作、连续扫掠与实物配合仍不在通过范围。

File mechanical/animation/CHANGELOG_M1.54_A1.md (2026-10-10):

# V1.2-M1.54-A1

由 M1.54 当前模型重新生成 22 步、85.75 秒、1280×720、24 fps 的装配工程和完整 MP4，EEVEE 16 samples。CAM 整板 USB 朝机器人右侧，保留原四孔／螺钉；动画采用向前错开 2 mm 的下放路径，在高 8 mm 处停留预接插头后再落座。没有添加未知的成品插头；完整带线装配仍未完成。

逐件核对模型／动画终态，实际编码文件回读通过。CAM 阶段另外检查了 471 个半帧原生零件姿态，无穿插。证据见 studies/cam_right_adoption/animation_cam_readback.json。

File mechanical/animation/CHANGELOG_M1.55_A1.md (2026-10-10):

# M1.55-A1 装配动画更新

已应用用户批准的颈部装入 R2，源模型为 V1.2-M1.55。
只改变 Pitch_Yoke 内孔及后侧开放颈壁；其他 200 件原生零件和硬件位姿保持。

第 11 个播放章节展示离机从下方装入裸反力轴，再装试配五金、耳座螺母和 C 压板。
保存后的直线路径覆盖 100 mm、294 个连续区间，并回读 85 个半帧位置。
另将镜头隐藏的 102 件已装身体零件保留在原动画位姿，连续复核仍通过。
后续身体模块及防脱压板动画路径已重新检查。

最终视频：1280×720、24 fps、2100 帧、87.5 秒。
实发舵盘／花键／中心锁紧、完整带线装配、人手／夹具与 PA12 强度仍未验证。
视频是当前数字装配说明，manufacturing_release=false。

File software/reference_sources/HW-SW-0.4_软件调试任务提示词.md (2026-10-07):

请在 MORI 项目中完成可以独立推进的软件调试工程。当前硬件任务仍在同一项目中选型与核验，请先阅读本提示词和随附快照，再实施，不要只写计划。

工作目录：/Users/dean/Documents/MORI
硬件交接目录：/Users/dean/Documents/MORI/hardware/handoff
交接版本：HW-SW-0.4，2026-09-21。这是模块台架接口候选，尚未经过实物验证，也不是冻结的装机 BOM。

## 先读与并行边界

1. 阅读根目录 AGENTS.md、params.json、hardware/dimensions/MORI_硬件尺寸要求.md。
2. 阅读 hardware/handoff/firmware_baseline.zip、baseline_manifest.json 与本提示词。快照包含已能编译的 ESP-IDF 最小固件、安全状态机、主机测试和当前 pinmap/wiring。若software/尚未建立，解压到software/firmware_work/，将其中firmware/作为工作工程；若已存在，则先读hardware/handoff/并行软件更新提示.md和software/interface_change_requests.md，只合并差异，禁止解压覆盖已有修改。不要修改快照本身。
3. 软件新增与修改统一放到 software/。hardware/ 下的固件、BOM、GPIO、接线和设计文件仍由硬件任务维护。不要改根 params.json、Blender、STL、机械报告，不要与硬件任务同时编辑相同文件。
4. 所有接口变化写入 software/interface_change_requests.md，包含动机、原接口、新接口、受影响文件与兼容策略。硬件任务后续按变更单合并。禁止默默换 GPIO、传感器量程、编码器倍频、电池阈值或电机方向。
5. 本次不创建新任务、不运行另一代理、不连接或自动烧录未知设备；用户之后明确提供实物端口时再进行对应操作。

## 产品和机械约束

MORI 是纯两轮主动自平衡机器人，只有两个带正交编码器的有刷直流轮电机和一个头部位置舵机。无第三接地点。运行时停住仍需平衡；断电会倒下。不加入摄像头、雷达、语音 AI、自动回充或手机 App。

头 Ø100、身体 Ø140、轮 Ø95×18、轮距138、腹部离地20 mm。当前两轮通过1:1带传动接独立6 mm轮轴，绝不是电机直接承载轮子。带轮实际齿数、皮带弹性、摩擦及齿隙尚未测量。

Blender 坐标 X左右、前方-Y、Z上；控制坐标采用右手系 x前、y左、z上。换算：x_control=-Y_Blender，y_control=X_Blender，z_control=Z_Blender。注意模型L对象在X负侧：控制left对应模型Wheel_R/Motor_R，控制right对应模型L；线束按控制左右标记。IMU原始轴到控制轴的安装旋转矩阵仍须六面静态和手动俯仰实测确认，不能仅根据PCB丝印推定。

## 软件接口候选

- MCU：Espressif ESP32-S3-DevKitC-1-N8R8 v1.1，8 MB Flash、8 MB Octal PSRAM，单主控。v1.1 RGB在GPIO38；旧版RGB48会与急停冲突。开发板不能直接装入现有55×24×7 mm占位，先外置台架，不得自动替换成脚数更少的小板。
- ESP-IDF v5.5.2，干净安装 /Users/dean/esp/esp-idf。使用项目 dependencies.lock 锁定依赖；不要未经说明升级。
- 两轮主候选：Pololu #4863，25D MP 12V、精确减速比20.4086667:1（22³×23/(12×10³)）、48 CPR编码器。2S电压驱动，必须保留0.39Ω限流。当前实体体积+器件质量预算约1.0 kg；Pololu #5216小电机已撤回主推荐，不能沿用旧参数。
- 编码器：每电机转48计数，已经包含A/B双通道全部边沿x4；减速器输出979.616计数/转。暂定带传动1:1，每计数 π×0.095/979.616≈0.00030466 m。不得再乘4。PCNT两单元、每单元两通道；低速测速使用8帧时间窗口。
- 新编码器必须使用3.5–20V供电，选DEVKIT_5V供电（USB诊断时也可用）；A/B输出0～Vcc，不能直接接ESP32！每条A/B先过3.3V供电的SN74LVC14AD（输入容忍5.5V）。A/B同时反相不改变相序，实际方向仍必须实测。接线表的J4/J5是自定义XH6重压端子线序，不等于原厂六针排母线序。
- 驱动：Pololu #2130 DRV8833，PWM20 kHz。nSLEEP低禁用；输入00滑行、10正向、01反向、11制动。初版使用一端PWM另一端低的快衰减方式。拆除模块nSLEEP上拉并加下拉、0.39Ω电流限制改装，以及外部看门狗/急停逻辑，必须实测通过才可使能。GPIO ARM 不等于直接绕过硬件安全链。
- IMU：Adafruit #4438 LSM6DSOX，I2C 400 kHz、地址0x6A、WHO_AM_I=0x6C，INT1陀螺DRDY 416 Hz，±2g、±500°/s。装在刚性机身；其25.6×17.8×4.6 mm模块目前不能放进16×16×4 mm占位。姿态任务为I2C唯一拥有者。
- 监测：Adafruit #904 INA219，0x40、0.1Ω，读取有符号电机母线电流；它不是每绕组相电流。电池ADC 30k/10k分压；两电机NTC为10k、B3380、10k上拉，需开短路检测与标定。
- 头部：暂定DFRobot SER0037 270°位置舵机，50 Hz、500–2500 us、中心1500 us，5 V独立支路。当前外啮合传动半径8:14，头部±60°需要舵机总210°；不能使用FS90或连续旋转舵机。标称映射head_angle→servo_angle=-1.75×head_angle；脉宽约1500−12.963×head_angle(us)。中心、方向、实际有效范围均未测。台架初始软件上限±50°，拆传动先找中心，再逐步±10°验证。CONFIG_MORI_HEAD_VERIFIED默认为n；未签字前拒绝head命令、保持无PWM。
- 屏幕：当前编译验证后端为Waveshare #19192 / GC9A01、SPI240×240、有效Ø32.4 mm，仅用于台架验证。机械要求有效Ø60 / 遮罩开口Ø58，最终圆屏仍在选型。务必把表情逻辑与面板驱动分离，提供无屏/模拟后端、可变分辨率与圆形裁切；不要把小屏写成最终整张黑脸，也不要将RGB并行屏当SPI屏。
- 电池：暂按普通4.2V满充电芯的2S，8.4 V满充、6.8 V告警/禁止新解锁、6.6 V请求支撑、6.0 V严重欠压禁用。成品电池尺寸/保护/回灌路径待确认；软件阈值是验证起点，不能替代BMS、保险、匹配充电器与急停。

## GPIO 候选（须与快照 board.h / pinmap.csv 一致）

电池ADC1；左NTC2；右NTC4；左桥IN1/IN2=5/6；右桥IN1/IN2=7/8；左编码A/B=9/10；右编码A/B=11/12；LCD MOSI/CLK/CS=13/14/15；IMU INT=16；I2C SDA/SCL=17/18；ARM=21；LCD DC/RST=39/40；头PWM=41；软件心跳=42；驱动nFAULT=47；ESTOP_OK=48。

USB-UART调试时先拔掉整个J12逻辑降压模块线束，保持J14连接，由USB经DevKit 5V脚/J14供逻辑与编码器5V；独立电池可供电机/头；不要违反厂家供电互斥要求并接USB和外接5V，初版禁Wi-Fi并控制USB逻辑电流<500mA。保留USB原生19/20、USB-UART43/44；不用启动脚0/3/45/46，不用N8R8占用35/36/37。39–42已使用，因此外部JTAG不可同时占这些脚。不要默认还有I2S/第二屏/更多传感器的空闲脚。初始左右驱动和编码器符号只是待验证常量，不视为实测结论。

## 先完成无需实物的工作

A. 复现现有构建及主机测试，保存真实命令、工具版本、退出码、日志和Git/文件哈希。当前基线已有一次ESP-IDF构建成功和163条主机断言通过；版本0.4已更新电机计数常量，你仍需复现自己的版本。不得将这些记录当成硬件成功。

B. 审查并完善安全状态机，保留DISARMED→CALIBRATING→READY→BENCH/BALANCE及锁存FAULT。启动/复位/下载默认为禁用。台架模式≤12%占空比，最长200 ms且命令不能延长期限。平衡功能与已核验功率级两个编译开关均默认关闭；增益默认0；只有显式解锁才允许出力。

C. 完成串口调试工具：协议版本、设备信息、带时间戳采集、CSV回放、参数范围校验、命令明确ACK/REJECT、故障码解释、延迟/抖动分位数与最大值、丢帧/日志丢弃计数。现有文本协议可兼容扩展，不要自动发arm、confirm_signs、gains或ack。严格拒绝NaN/Inf/多余字段/溢出/截断。无串口时提供模拟数据源，所有模拟记录文件名和元数据标SIMULATED。

D. 用可注入时钟与模拟HAL覆盖：IMU无响应/旧样本、编码器跳变/断线、ADC/NTC开短路、过流、过温、欠压、过压、持续饱和、严重倾倒、nFAULT、急停、控制超时、命令队列溢出与复位。验证FAULT锁存、恢复需人工确认、不自动重启。发现基线问题应先写能复现的问题测试，再修复，不机械复制实现写断言。

E. 输出实时性分析与测量钩子。初始姿态416Hz，周期约2.404ms；把采样/器件滤波、I2C传输、调度唤醒、姿态融合、控制、PWM生效分开统计。目标任务计算+传输≤1.8ms，实测最大值必须报告；8ms IMU超时仅是严重故障后备，不是正常延迟预算。外部心跳只在健康控制帧完成后软件更新，禁止自由运行PWM喂狗。屏幕SPI DMA分块、日志及无线跑低优先级，不持有控制锁、不在实时路径打印或动态分配。还没有硬件时填NOT_TESTED，不能伪造时序数值。

F. 实现可替换的IMU安装矩阵、编码器符号和输出符号配置，并提供明确的离线方向检查说明。姿态量SI单位，pitch正值定义与轮正向一致；用物理推理/简化仿真检查控制符号。保留一种一致的控制结构：慢速速度环生成有限倾角参考，姿态PD/状态反馈唯一产生公共轮力矩，差动转向只用剩余输出余量。不要让独立轮速PID和平衡PID叠加争抢输出。没有辨识数据不得给出“已调好”的PID/LQR参数。

G. 最小表情显示、头部平滑轨迹与主控制解耦。只对运动目标和头轨迹限加速度；不对平衡纠偏输出加粗暴全局慢斜率。头部误差/线缆阻力、屏幕/Wi-Fi负载后续逐项加入实测。

## 必须维持的语义

- stop：速度/转向目标归零，健康时继续本地平衡。
- 500ms通信中断：撤销运动目标，不能立刻关电机。
- disarm、硬件急停、严重故障：禁用驱动，允许倒下；只有有支撑时安排主动disarm。
- 低电量：提前告警，请求放入托架/人工支撑，不承诺自行停稳或回充。
- 严禁无线停止代替硬件急停；严禁为让测试通过移除安全门或写死“已确认”。

## 交付与验收

请实际生成 software/README.md、独立固件工作副本、串口采集/回放工具、模拟HAL与安全/协议测试、调试手册、真实构建日志和 software/interface_change_requests.md。将功能、单元/仿真验证、实物验证分栏，统一PASS / FAIL / NOT_TESTED / NOT_APPLICABLE。

实物调试手册按断电→限流且电机禁用→单模块→悬空单电机低占空→双电机/回灌/急停→台架辨识→防摔保护下平衡→安全场地低速运动递进。每步有前置条件、命令、观测量、阈值、停止条件与记录模板。任何旋转/上电/稳态/热/自由平衡效果，没有真实设备证据就标NOT_TESTED。

最后列出已完成的可运行命令、实际通过的测试、仍需硬件任务决定的接口、仍需人工实测的项目。不要声称机器人已经能平衡，不要只给建议而不落地文件。

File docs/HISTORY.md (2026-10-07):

# 历史资料索引

当前设计看 [M1.52 状态](CURRENT_STATUS.md)，以下目录用于追溯。`before_*` 表示改动前保存的快照；目录名称不代表该方案已采用。旧版本尺寸、接口及 PASS 不能覆盖当前合同。

| 历史范围 | 入口与边界 |
|---|---|
| 归档前首页 | [原 README](archive/README_before_2026-10-06.md)，保留其旧内容和原路径文字，链接以原项目根目录为基准 |
| A0 初始机械 | 根目录 params.json、scripts/、models/、renders/、exports/，不定义 V1.2 |
| V1 旧硬件 | [hardware/v1](https://github.com/deanxizian/MORI/tree/48fe22aa75554c9d7bb237e2d2dcacca7f83dde1/hardware/v1)，不作为当前接线依据 |
| 旧软件台架 | [software/README](../software/README.md)，HW-SW-0.4／A0 历史 |
| V1.2 PCB 修订 | [hardware/v1_2/kicad](../hardware/v1_2/kicad/)，当前版本以硬件首页列出的四板为准 |
| 机械研究与候选 | [mechanical/studies](https://github.com/deanxizian/MORI/tree/48fe22aa75554c9d7bb237e2d2dcacca7f83dde1/mechanical/studies)，包含成功、失败和未采用方案 |

历史脚本、参数与较小报告保留在 Git 中；旧模型、重复图片、视频和大型计算数据保留本地，未全部上传。详见 [归档范围](GITHUB_ARCHIVE.md)。

## 机械快照目录

| 目录 | 记录入口 |
|---|---|
| V1-A_before_visual_refinement | [参数／记录](https://github.com/deanxizian/MORI/blob/48fe22aa75554c9d7bb237e2d2dcacca7f83dde1/mechanical/revisions/V1-A_before_visual_refinement/README.md) |
| V1-A2_before_wheel_inset | [参数／记录](https://github.com/deanxizian/MORI/blob/48fe22aa75554c9d7bb237e2d2dcacca7f83dde1/mechanical/revisions/V1-A2_before_wheel_inset/README.md) |
| V1.2-M1_before_purchased_dimensions | [参数／记录](https://github.com/deanxizian/MORI/blob/48fe22aa75554c9d7bb237e2d2dcacca7f83dde1/mechanical/revisions/V1.2-M1_before_purchased_dimensions/AGENTS.md) |
| V1.2-M1.1_iteration_diagnostics | [参数／记录](https://github.com/deanxizian/MORI/blob/48fe22aa75554c9d7bb237e2d2dcacca7f83dde1/mechanical/revisions/V1.2-M1.1_iteration_diagnostics/README.md) |
| V1.2-M1.1_before_structure_simplification | [参数／记录](https://github.com/deanxizian/MORI/blob/48fe22aa75554c9d7bb237e2d2dcacca7f83dde1/mechanical/revisions/V1.2-M1.1_before_structure_simplification/AGENTS.md) |
| V1.2-M1.2_before_monocoque | [参数／记录](https://github.com/deanxizian/MORI/blob/48fe22aa75554c9d7bb237e2d2dcacca7f83dde1/mechanical/revisions/V1.2-M1.2_before_monocoque/AGENTS.md) |
| V1.2-M1.3_before_simple_modules | [参数／记录](https://github.com/deanxizian/MORI/blob/48fe22aa75554c9d7bb237e2d2dcacca7f83dde1/mechanical/revisions/V1.2-M1.3_before_simple_modules/AGENTS.md) |
| V1.2-M1.4_before_lower_deck | [参数／记录](https://github.com/deanxizian/MORI/blob/48fe22aa75554c9d7bb237e2d2dcacca7f83dde1/mechanical/revisions/V1.2-M1.4_before_lower_deck/AGENTS.md) |
| V1.2-M1.5_before_flat_head | [参数／记录](https://github.com/deanxizian/MORI/blob/48fe22aa75554c9d7bb237e2d2dcacca7f83dde1/mechanical/revisions/V1.2-M1.5_before_flat_head/AGENTS.md) |
| V1.2-M1.6_before_wheels_camera | [参数／记录](https://github.com/deanxizian/MORI/blob/48fe22aa75554c9d7bb237e2d2dcacca7f83dde1/mechanical/revisions/V1.2-M1.6_before_wheels_camera/AGENTS.md) |
| V1.2-M1.7_before_lower_body | [参数／记录](https://github.com/deanxizian/MORI/blob/48fe22aa75554c9d7bb237e2d2dcacca7f83dde1/mechanical/revisions/V1.2-M1.7_before_lower_body/AGENTS.md) |
| V1.2-M1.8_before_belly_relayout | [参数／记录](https://github.com/deanxizian/MORI/blob/48fe22aa75554c9d7bb237e2d2dcacca7f83dde1/mechanical/revisions/V1.2-M1.8_before_belly_relayout/AGENTS.md) |
| V1.2-M1.9_before_detail_fit | [参数／记录](https://github.com/deanxizian/MORI/blob/48fe22aa75554c9d7bb237e2d2dcacca7f83dde1/mechanical/revisions/V1.2-M1.9_before_detail_fit/AGENTS.md) |
| V1.2-M1.10_before_level_head | [参数／记录](https://github.com/deanxizian/MORI/blob/48fe22aa75554c9d7bb237e2d2dcacca7f83dde1/mechanical/revisions/V1.2-M1.10_before_level_head/AGENTS.md) |
| V1.2-M1.11_before_surface_face | [参数／记录](https://github.com/deanxizian/MORI/blob/48fe22aa75554c9d7bb237e2d2dcacca7f83dde1/mechanical/revisions/V1.2-M1.11_before_surface_face/AGENTS.md) |
| V1.2-M1.12_before_part_consolidation | [参数／记录](https://github.com/deanxizian/MORI/blob/48fe22aa75554c9d7bb237e2d2dcacca7f83dde1/mechanical/revisions/V1.2-M1.12_before_part_consolidation/AGENTS.md) |
| V1.2-M1.13_before_wheel_interface | [参数／记录](https://github.com/deanxizian/MORI/blob/48fe22aa75554c9d7bb237e2d2dcacca7f83dde1/mechanical/revisions/V1.2-M1.13_before_wheel_interface/snapshot.json) |
| V1.2-M1.14_before_flush_yaw_mount | [参数／记录](https://github.com/deanxizian/MORI/blob/48fe22aa75554c9d7bb237e2d2dcacca7f83dde1/mechanical/revisions/V1.2-M1.14_before_flush_yaw_mount/snapshot.json) |
| V1.2-M1.15_before_battery_mount_repair | [参数／记录](https://github.com/deanxizian/MORI/blob/48fe22aa75554c9d7bb237e2d2dcacca7f83dde1/mechanical/revisions/V1.2-M1.15_before_battery_mount_repair/snapshot.json) |
| V1.2-M1.16_before_power_seat_cleanup | [参数／记录](https://github.com/deanxizian/MORI/blob/48fe22aa75554c9d7bb237e2d2dcacca7f83dde1/mechanical/revisions/V1.2-M1.16_before_power_seat_cleanup/snapshot.json) |
| V1.2-M1.17_before_wider_battery_tray | [参数／记录](https://github.com/deanxizian/MORI/blob/48fe22aa75554c9d7bb237e2d2dcacca7f83dde1/mechanical/revisions/V1.2-M1.17_before_wider_battery_tray/snapshot.json) |
| V1.2-M1.18_before_no_mic_ducts | [参数／记录](https://github.com/deanxizian/MORI/blob/48fe22aa75554c9d7bb237e2d2dcacca7f83dde1/mechanical/revisions/V1.2-M1.18_before_no_mic_ducts/snapshot.json) |
| V1.2-M1.19_before_fusheng_speaker | [参数／记录](https://github.com/deanxizian/MORI/blob/48fe22aa75554c9d7bb237e2d2dcacca7f83dde1/mechanical/revisions/V1.2-M1.19_before_fusheng_speaker/snapshot.json) |
| V1.2-M1.20_before_compact_yaw_stops | [参数／记录](https://github.com/deanxizian/MORI/blob/48fe22aa75554c9d7bb237e2d2dcacca7f83dde1/mechanical/revisions/V1.2-M1.20_before_compact_yaw_stops/snapshot.json) |
| V1.2-M1.21_before_crossbolt_joint | [参数／记录](https://github.com/deanxizian/MORI/blob/48fe22aa75554c9d7bb237e2d2dcacca7f83dde1/mechanical/revisions/V1.2-M1.21_before_crossbolt_joint/snapshot.json) |
| V1.2-M1.22_before_populated_pcbs | [参数／记录](https://github.com/deanxizian/MORI/blob/48fe22aa75554c9d7bb237e2d2dcacca7f83dde1/mechanical/revisions/V1.2-M1.22_before_populated_pcbs/snapshot.json) |
| V1.2-M1.23_before_head_cleanup | [参数／记录](https://github.com/deanxizian/MORI/blob/48fe22aa75554c9d7bb237e2d2dcacca7f83dde1/mechanical/revisions/V1.2-M1.23_before_head_cleanup/snapshot.json) |
| V1.2-M1.23_before_animation_video | [参数／记录](https://github.com/deanxizian/MORI/blob/48fe22aa75554c9d7bb237e2d2dcacca7f83dde1/mechanical/revisions/V1.2-M1.23_before_animation_video/snapshot.json) |
| V1.2-M1.24_before_planar_head_cleanup | [参数／记录](https://github.com/deanxizian/MORI/blob/48fe22aa75554c9d7bb237e2d2dcacca7f83dde1/mechanical/revisions/V1.2-M1.24_before_planar_head_cleanup/snapshot.json) |
| V1.2-M1.25_before_drive_cleanup | [参数／记录](https://github.com/deanxizian/MORI/blob/48fe22aa75554c9d7bb237e2d2dcacca7f83dde1/mechanical/revisions/V1.2-M1.25_before_drive_cleanup/snapshot.json) |
| V1.2-M1.26_before_head_corner_chamfer | [参数／记录](https://github.com/deanxizian/MORI/blob/48fe22aa75554c9d7bb237e2d2dcacca7f83dde1/mechanical/revisions/V1.2-M1.26_before_head_corner_chamfer/snapshot.json) |
| V1.2-M1.27_before_broad_head_folds | [参数／记录](https://github.com/deanxizian/MORI/blob/48fe22aa75554c9d7bb237e2d2dcacca7f83dde1/mechanical/revisions/V1.2-M1.27_before_broad_head_folds/snapshot.json) |
| V1.2-M1.28_before_surface_normals | [参数／记录](https://github.com/deanxizian/MORI/blob/48fe22aa75554c9d7bb237e2d2dcacca7f83dde1/mechanical/revisions/V1.2-M1.28_before_surface_normals/snapshot.json) |
| V1.2-M1.29_before_servo_detail | [参数／记录](https://github.com/deanxizian/MORI/blob/48fe22aa75554c9d7bb237e2d2dcacca7f83dde1/mechanical/revisions/V1.2-M1.29_before_servo_detail/snapshot.json) |
| V1.2-M1.30_before_seat_foot_cleanup | [参数／记录](https://github.com/deanxizian/MORI/blob/48fe22aa75554c9d7bb237e2d2dcacca7f83dde1/mechanical/revisions/V1.2-M1.30_before_seat_foot_cleanup/AGENTS.md) |
| V1.2-M1.31_before_yaw_pad_centering | [参数／记录](https://github.com/deanxizian/MORI/blob/48fe22aa75554c9d7bb237e2d2dcacca7f83dde1/mechanical/revisions/V1.2-M1.31_before_yaw_pad_centering/AGENTS.md) |
| V1.2-M1.32_before_waveshare_detail | [参数／记录](https://github.com/deanxizian/MORI/blob/48fe22aa75554c9d7bb237e2d2dcacca7f83dde1/mechanical/revisions/V1.2-M1.32_before_waveshare_detail/AGENTS.md) |
| V1.2-M1.33_before_simple_head_mounts | [参数／记录](https://github.com/deanxizian/MORI/blob/48fe22aa75554c9d7bb237e2d2dcacca7f83dde1/mechanical/revisions/V1.2-M1.33_before_simple_head_mounts/AGENTS.md) |
| V1.2-M1.34_before_assembly_completion | [参数／记录](https://github.com/deanxizian/MORI/blob/48fe22aa75554c9d7bb237e2d2dcacca7f83dde1/mechanical/revisions/V1.2-M1.34_before_assembly_completion/AGENTS.md) |
| V1.2-M1.35_before_cap_edge_cleanup | [参数／记录](https://github.com/deanxizian/MORI/blob/48fe22aa75554c9d7bb237e2d2dcacca7f83dde1/mechanical/revisions/V1.2-M1.35_before_cap_edge_cleanup/AGENTS.md) |
| V1.2-M1.36_before_SP3040 | [参数／记录](https://github.com/deanxizian/MORI/blob/48fe22aa75554c9d7bb237e2d2dcacca7f83dde1/mechanical/revisions/V1.2-M1.36_before_SP3040/AGENTS.md) |
| V1.2-M1.37_before_readiness_completion | [参数／记录](https://github.com/deanxizian/MORI/blob/48fe22aa75554c9d7bb237e2d2dcacca7f83dde1/mechanical/revisions/V1.2-M1.37_before_readiness_completion/snapshot.json) |
| V1.2-M1.38_before_prearrival | [参数／记录](https://github.com/deanxizian/MORI/blob/48fe22aa75554c9d7bb237e2d2dcacca7f83dde1/mechanical/revisions/V1.2-M1.38_before_prearrival/snapshot.json) |
| V1.2-M1.39_before_mount_root_cleanup | [参数／记录](https://github.com/deanxizian/MORI/blob/48fe22aa75554c9d7bb237e2d2dcacca7f83dde1/mechanical/revisions/V1.2-M1.39_before_mount_root_cleanup/AGENTS.md) |
| V1.2-M1.40_before_display_frame_flush | [参数／记录](https://github.com/deanxizian/MORI/blob/48fe22aa75554c9d7bb237e2d2dcacca7f83dde1/mechanical/revisions/V1.2-M1.40_before_display_frame_flush/snapshot.json) |
| V1.2-M1.41_before_interface_completion | [参数／记录](https://github.com/deanxizian/MORI/blob/48fe22aa75554c9d7bb237e2d2dcacca7f83dde1/mechanical/revisions/V1.2-M1.41_before_interface_completion/AGENTS.md) |
| V1.2-M1.42_before_six_issue_fixes | [参数／记录](https://github.com/deanxizian/MORI/blob/48fe22aa75554c9d7bb237e2d2dcacca7f83dde1/mechanical/revisions/V1.2-M1.42_before_six_issue_fixes/AGENTS.md) |
| V1.2-M1.43_before_head_retention_M1.44 | [参数／记录](https://github.com/deanxizian/MORI/blob/48fe22aa75554c9d7bb237e2d2dcacca7f83dde1/mechanical/revisions/V1.2-M1.43_before_head_retention_M1.44/AGENTS.md) |
| V1.2-M1.43_before_animation_A2 | [参数／记录](https://github.com/deanxizian/MORI/blob/48fe22aa75554c9d7bb237e2d2dcacca7f83dde1/mechanical/revisions/V1.2-M1.43_before_animation_A2/snapshot.json) |
| V1.2-M1.44_before_P5R7_M1.45 | [参数／记录](https://github.com/deanxizian/MORI/blob/48fe22aa75554c9d7bb237e2d2dcacca7f83dde1/mechanical/revisions/V1.2-M1.44_before_P5R7_M1.45/AGENTS.md) |
| V1.2-M1.46_before_approved_thin_cleanup | [参数／记录](https://github.com/deanxizian/MORI/blob/48fe22aa75554c9d7bb237e2d2dcacca7f83dde1/mechanical/revisions/V1.2-M1.46_before_approved_thin_cleanup/AGENTS.md) |
| V1.2-M1.47_before_camera_CAM_approval | [参数／记录](https://github.com/deanxizian/MORI/blob/48fe22aa75554c9d7bb237e2d2dcacca7f83dde1/mechanical/revisions/V1.2-M1.47_before_camera_CAM_approval/config/geometry.json) |
| V1.2-M1.48_before_neck_capacity | [参数／记录](https://github.com/deanxizian/MORI/blob/48fe22aa75554c9d7bb237e2d2dcacca7f83dde1/mechanical/revisions/V1.2-M1.48_before_neck_capacity/AGENTS.md) |
| V1.2-M1.49_before_CAM_entry_fix | [参数／记录](https://github.com/deanxizian/MORI/blob/48fe22aa75554c9d7bb237e2d2dcacca7f83dde1/mechanical/revisions/V1.2-M1.49_before_CAM_entry_fix/config/geometry.json) |
| V1.2-M1.49_C5_before_keeper_wall | [参数／记录](https://github.com/deanxizian/MORI/blob/48fe22aa75554c9d7bb237e2d2dcacca7f83dde1/mechanical/revisions/V1.2-M1.49_C5_before_keeper_wall/config/geometry.json) |
| V1.2-M1.50_before_body_split | [参数／记录](https://github.com/deanxizian/MORI/blob/48fe22aa75554c9d7bb237e2d2dcacca7f83dde1/mechanical/revisions/V1.2-M1.50_before_body_split/AGENTS.md) |
| V1.2-M1.51_before_nut_alignment | [参数／记录](https://github.com/deanxizian/MORI/blob/48fe22aa75554c9d7bb237e2d2dcacca7f83dde1/mechanical/revisions/V1.2-M1.51_before_nut_alignment/AGENTS.md) |
| V1-A3_before_wheel_resize | [参数／记录](https://github.com/deanxizian/MORI/blob/48fe22aa75554c9d7bb237e2d2dcacca7f83dde1/mechanical/revisions/V1-A3_before_wheel_resize/README.md) |
| V1-A4_before_V1_2 | [参数／记录](https://github.com/deanxizian/MORI/blob/48fe22aa75554c9d7bb237e2d2dcacca7f83dde1/mechanical/revisions/V1-A4_before_V1_2/AGENTS.md) |
| M1.9_unreleased_report_audit | [参数／记录](https://github.com/deanxizian/MORI/blob/48fe22aa75554c9d7bb237e2d2dcacca7f83dde1/mechanical/revisions/M1.9_unreleased_report_audit/README.md) |
| M1.14_development_intermediate | [参数／记录](https://github.com/deanxizian/MORI/blob/48fe22aa75554c9d7bb237e2d2dcacca7f83dde1/mechanical/revisions/M1.14_development_intermediate/README.md) |
| M1.22_before_P5R1_receipt | 本地历史目录，二进制未全部上传 |

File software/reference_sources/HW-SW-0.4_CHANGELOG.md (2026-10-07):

# HW-SW-0.4 — 2026-09-21

累积取代0.2/0.3：根据已提供的Blender体积重新估算质量，轮电机主选改为Pololu4863 25D MP12V 20.4086667:1。轮端x4计数从1204.44改为979.616。GPIO不变。编码器5V供电、A/B经SN74LVC14AD转为3.3V；不再使用小电机SH6线束。轮子仍是1:1皮带传动独立轴。USB调试前拔J12逻辑降压模块线束，J14保持连接使USB能供编码器5V；不再拔J14。母线吸能R14从24.3k改25.5k0.1%，GPIO与软件故障阈值不变。主机测试脚本改为位置相对，可在快照副本运行。其他软件接口和安全状态语义保持。

如果软件任务已经复制0.2/0.3，请按并行软件更新提示.md合并参数/接线说明，保留已完成的软件修改；重新构建并运行测试。ICR-001中把979.616改回1204.44的提案针对旧电机，当前4863不采用。不得把电机CPR与齿轮比硬编码在多个文件。

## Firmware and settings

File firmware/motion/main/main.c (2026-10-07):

#include "peripherals.h"
#include "board.h"
#include "mount_config.h"
#include "mori_runtime.h"
#include "mori_telemetry.h"
#include "mori_ui.h"
#include "sdkconfig.h"
#include "esp_timer.h"
#include "esp_log.h"
#include "esp_app_desc.h"
#include "esp_task_wdt.h"
#include "driver/uart.h"
#include "freertos/FreeRTOS.h"
#include "freertos/task.h"
#include "freertos/queue.h"
#include <stdio.h>
#include <inttypes.h>
#include <stdatomic.h>

static TaskHandle_t control_handle;
static QueueHandle_t logs,parse_replies,head_updates;
static portMUX_TYPE mux=portMUX_INITIALIZER_UNLOCKED;
static uint64_t imu_edge_us;static unsigned irq_fault;
static mori_runtime_t runtime;
static atomic_bool ui_fault;
static atomic_uint parse_drops;
static bool peripherals_ok;
static mori_state_t published_state=MORI_DISARMED;
static uint32_t events,frame_number,sample_missed,log_dropped;
static uint64_t frame_begin,edge,last_begin;
static mori_sample_t cached;
typedef struct {uint32_t id;mori_reason_t reason;} parse_reply_t;
typedef struct {uint64_t us;float target;bool enabled;uint32_t revision;} head_update_t;

static void IRAM_ATTR data_ready(void *arg){
 (void)arg;uint64_t now=esp_timer_get_time();
 portENTER_CRITICAL_ISR(&mux);imu_edge_us=now;portEXIT_CRITICAL_ISR(&mux);
 BaseType_t wake=pdFALSE;if(control_handle)vTaskNotifyGiveFromISR(control_handle,&wake);if(wake)portYIELD_FROM_ISR();
}
static void IRAM_ATTR fault_edge(void *arg){
 gpio_set_level(PIN_ARM,0); /* external ESTOP/watchdog gating is still mandatory */
 portENTER_CRITICAL_ISR(&mux);irq_fault|=(unsigned)(uintptr_t)arg;portEXIT_CRITICAL_ISR(&mux);
}
static uint64_t clock_now(void *ctx){(void)ctx;return esp_timer_get_time();}
static void apply(void *ctx,mori_output_t out){(void)ctx;motor_apply(out);if(!motor_io_ok())mori_trip(&runtime.core,MF_DRIVER);}
static void heartbeat_complete(void *ctx,bool level){
 (void)ctx;
 if(gpio_get_level(PIN_ESTOP)&&gpio_get_level(PIN_FAULT))gpio_set_level(PIN_HEARTBEAT,level);
 else gpio_set_level(PIN_ARM,0);
}
static void after_apply(void *ctx){
 (void)ctx;atomic_store(&ui_fault,runtime.core.state==MORI_FAULT);
 head_update_t h={.us=frame_begin,.target=runtime.head_target,.enabled=runtime.head_active,.revision=runtime.head_revision};xQueueOverwrite(head_updates,&h);
 esp_task_wdt_reset();
}
static void sample(void *ctx,mori_sample_t *s,mori_timing_t *timing){
 (void)ctx;
 /* Publish the preceding COMPLETED frame, never hold a control lock or print. */
 if(runtime.frames&&(runtime.frames%40==0||runtime.core.state!=published_state)){
  mori_log_t log;mori_log_snapshot(&log,&runtime,sample_missed,log_dropped,atomic_load(&parse_drops));
  if(xQueueSend(logs,&log,0)!=pdTRUE)log_dropped++;
  else published_state=runtime.core.state;
 }
 *s=cached;uint64_t io=esp_timer_get_time();
 unsigned irq;portENTER_CRITICAL(&mux);irq=irq_fault;irq_fault=0;portEXIT_CRITICAL(&mux);
 s->driver_ok=gpio_get_level(PIN_FAULT)&&!(irq&1)&&motor_io_ok();s->estop_ok=gpio_get_level(PIN_ESTOP)&&!(irq&2);
 if(irq)mori_trip(&runtime.core,(irq&2)?MF_ESTOP:MF_DRIVER);
 s->imu_us=edge;s->imu_ok=peripherals_ok&&events==1&&imu_read(s)==ESP_OK;
 timing->imu_io_us=esp_timer_get_time()-io;
 timing->wake_us=edge<=frame_begin?(uint32_t)(frame_begin-edge):UINT32_MAX;
 io=esp_timer_get_time();float dt=last_begin?(frame_begin-last_begin)*1e-6f:1.f/416;
 s->encoders_ok=encoders_read(s,dt);timing->encoder_us=esp_timer_get_time()-io;
 if(frame_number%8==0){io=esp_timer_get_time();s->monitor_ok=peripherals_ok&&monitors_read(s)==ESP_OK;timing->monitor_io_us=esp_timer_get_time()-io;}
 cached=*s;
}
static void head_task(void *arg){
 (void)arg;head_update_t u={0};mori_head_trajectory_t trajectory={0};mori_head_guard_t guard={0};uint64_t last=esp_timer_get_time();
 while(1){
  xQueueReceive(head_updates,&u,pdMS_TO_TICKS(20));uint64_t now=esp_timer_get_time();float dt=(now-last)*1e-6f;last=now;
  bool fresh=now>=u.us&&now-u.us<=50000&&gpio_get_level(PIN_ESTOP)&&gpio_get_level(PIN_FAULT)&&!atomic_load(&ui_fault);
  bool allowed=mori_head_guard(&guard,u.revision,u.enabled,fresh,dt);
  if(!allowed){head_disable();trajectory.velocity=0;}
  else{mori_head_step(&trajectory,u.target,dt);if(!head_set(trajectory.position)){head_disable();guard.blocked=true;guard.blocked_revision=u.revision;}}
  vTaskDelay(pdMS_TO_TICKS(20));
 }
}
static void control_task(void *arg){
 (void)arg;
 /* This task owns ALL I2C initialization and transactions, including INA219. */
 peripherals_ok=sensors_init()==ESP_OK;
 esp_log_level_set("i2c.master",ESP_LOG_NONE); /* runtime driver errors are telemetry */
 esp_log_level_set("adc_oneshot",ESP_LOG_NONE);esp_log_level_set("adc_cali",ESP_LOG_NONE);
 esp_log_level_set("pcnt",ESP_LOG_NONE);esp_log_level_set("ledc",ESP_LOG_NONE);
 const mori_mount_t mount=MORI_MOUNT_INITIALIZER;
 if(!mori_mount_valid(&mount)){peripherals_ok=false;mori_trip(&runtime.core,MF_CONFIG);}
 ESP_ERROR_CHECK(esp_task_wdt_add(NULL));
 mori_hal_t hal={.now_us=clock_now,.sample=sample,.apply=apply,.heartbeat=heartbeat_complete,.after_apply=after_apply};
 while(1){
  events=ulTaskNotifyTake(pdTRUE,pdMS_TO_TICKS(8));frame_begin=esp_timer_get_time();
  portENTER_CRITICAL(&mux);edge=imu_edge_us;portEXIT_CRITICAL(&mux);
  if(events>1)sample_missed+=events-1;
  if(!events)sample_missed++;
  mori_runtime_frame(&runtime,&hal); /* Includes UI queue copies and bookkeeping before healthy heartbeat. */
  last_begin=frame_begin;frame_number++;
 }
}
static void info(uint32_t id){
 printf("HEADER MORI/1 %s\n",MORI_CSV_HEADER);
 const esp_app_desc_t *app=esp_app_get_description();
 printf("INFO %"PRIu32" MORI/1 " MORI_SCALE_INFO_FORMAT " target=esp32s3 candidate=DevKitC-1-N8R8-v1.1 idf=%s baud=115200 sample_hz=416 telemetry_stride=40 configured_flash_mb=8 psram_enabled=0 physical=NOT_TESTED power_gate=%d balance_gate=%d head_gate=%d axes_gate=%d image_sha256=",id,MORI_SCALE_INFO_ARGS,app->idf_ver,runtime.core.cfg.power_verified,runtime.core.cfg.balance_enabled,runtime.head_verified,runtime.axes_verified);
 for(unsigned i=0;i<sizeof(app->app_elf_sha256);i++){printf("%02x",app->app_elf_sha256[i]);}
 puts("");
 const mori_mount_t mount=MORI_MOUNT_INITIALIZER;
 printf("MOUNT MORI/1 R=");for(int i=0;i<3;i++)for(int j=0;j<3;j++)printf("%s%.6f",i||j?",":"",mount.rotation[i][j]);
 printf(" encoder=%d,%d output=%d,%d axes_gate=%d\n",mount.encoder_sign[0],mount.encoder_sign[1],mount.motor_sign[0],mount.motor_sign[1],runtime.axes_verified);
}
static void logging_task(void *arg){
 (void)arg;info(0);
 while(1){
  parse_reply_t parse;while(xQueueReceive(parse_replies,&parse,0)==pdTRUE)printf("REJECT %"PRIu32" MORI/1 reason=%s\n",parse.id,mori_reason_name(parse.reason));
  mori_reply_t reply;while(mori_runtime_reply(&runtime,&reply)){
   if(reply.kind==MP_INFO&&reply.reason==MR_OK)info(reply.id);
   printf("%s %"PRIu32" MORI/1 reason=%s state=%s fault=%d\n",reply.reason==MR_OK?"ACK":"REJECT",reply.id,mori_reason_name(reply.reason),mori_state_name(reply.state),reply.fault);
  }
  mori_log_t log;if(xQueueReceive(logs,&log,pdMS_TO_TICKS(10))==pdTRUE)mori_log_print(stdout,&log);
 }
}
static void parse_reject(uint32_t id,mori_reason_t reason){
 parse_reply_t reply={id,reason};if(xQueueSend(parse_replies,&reply,0)!=pdTRUE)atomic_fetch_add(&parse_drops,1);
}
static void console_task(void *arg){
 (void)arg;mori_line_t line={0};mori_request_t req;mori_reason_t reason;uint8_t byte;
 ESP_ERROR_CHECK(uart_driver_install(UART_NUM_0,512,0,0,NULL,0));
 while(1){
  if(uart_read_bytes(UART_NUM_0,&byte,1,pdMS_TO_TICKS(20))==1){
   if(mori_line_feed(&line,byte,esp_timer_get_time(),&req,&reason)){
    if(reason!=MR_OK)parse_reject(req.id,reason);
    else if(!mori_runtime_enqueue(&runtime,req))parse_reject(req.id,MR_QUEUE);
   }
  }
  if(mori_line_expire(&line,esp_timer_get_time(),&reason))parse_reject(0,reason);
 }
}
void mori_legacy_bench_main(void){
 motor_init(); /* First peripheral action: ARM low and every wheel input low. */
 gpio_config_t input={.pin_bit_mask=(1ULL<<PIN_FAULT)|(1ULL<<PIN_ESTOP),.mode=GPIO_MODE_INPUT,.intr_type=GPIO_INTR_NEGEDGE};ESP_ERROR_CHECK(gpio_config(&input));
 ESP_ERROR_CHECK(gpio_install_isr_service(0));
 ESP_ERROR_CHECK(gpio_isr_handler_add(PIN_FAULT,fault_edge,(void*)1));ESP_ERROR_CHECK(gpio_isr_handler_add(PIN_ESTOP,fault_edge,(void*)2));
 ESP_ERROR_CHECK(encoders_init());head_init();
 mori_config_t cfg={0};bool head=false,axes=false;
#ifdef CONFIG_MORI_POWER_STAGE_VERIFIED
 cfg.power_verified=true;
#endif
#ifdef CONFIG_MORI_ENABLE_BALANCE
 cfg.balance_enabled=true;
#endif
#ifdef CONFIG_MORI_HEAD_VERIFIED
 head=true;
#endif
#ifdef CONFIG_MORI_AXES_VERIFIED
 axes=true;
#endif
 mori_runtime_init(&runtime,cfg,head,axes);atomic_init(&ui_fault,false);atomic_init(&parse_drops,0);
 logs=xQueueCreate(16,sizeof(mori_log_t));parse_replies=xQueueCreate(16,sizeof(parse_reply_t));head_updates=xQueueCreate(1,sizeof(head_update_t));configASSERT(logs&&parse_replies&&head_updates);
 gpio_config_t ir={.pin_bit_mask=1ULL<<PIN_IMU_INT,.mode=GPIO_MODE_INPUT,.intr_type=GPIO_INTR_POSEDGE};ESP_ERROR_CHECK(gpio_config(&ir));ESP_ERROR_CHECK(gpio_isr_handler_add(PIN_IMU_INT,data_ready,NULL));
 configASSERT(xTaskCreatePinnedToCore(control_task,"balance_io",6144,NULL,23,&control_handle,1)==pdPASS);
 configASSERT(xTaskCreatePinnedToCore(logging_task,"log",4096,NULL,2,NULL,0)==pdPASS);
 configASSERT(xTaskCreatePinnedToCore(console_task,"console",4096,NULL,3,NULL,0)==pdPASS);
 configASSERT(xTaskCreatePinnedToCore(head_task,"head",3072,NULL,2,NULL,0)==pdPASS);
 configASSERT(xTaskCreatePinnedToCore(display_task,"lcd",4096,&ui_fault,1,NULL,0)==pdPASS);
 /* No synthetic DRDY. An absent sensor remains unhealthy and cannot unlock. */
}

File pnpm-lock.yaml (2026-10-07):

lockfileVersion: '9.0'

settings:
  autoInstallPeers: true
  excludeLinksFromLockfile: false

importers:

  .:
    dependencies:
      '@capacitor/app':
        specifier: 7.0.1
        version: 7.0.1(@capacitor/core@7.2.0)
      '@capacitor/core':
        specifier: 7.2.0
        version: 7.2.0
      vue:
        specifier: 3.5.13
        version: 3.5.13(typescript@5.8.3)
    devDependencies:
      '@capacitor/android':
        specifier: 7.2.0
        version: 7.2.0(@capacitor/core@7.2.0)
      '@capacitor/cli':
        specifier: 7.2.0
        version: 7.2.0
      '@capacitor/ios':
        specifier: 7.2.0
        version: 7.2.0(@capacitor/core@7.2.0)
      '@playwright/test':
        specifier: 1.52.0
        version: 1.52.0
      '@types/node':
        specifier: 22.15.18
        version: 22.15.18
      '@vitejs/plugin-vue':
        specifier: 5.2.4
        version: 5.2.4(vite@6.3.5(@types/node@22.15.18))(vue@3.5.13(typescript@5.8.3))
      prettier:
        specifier: 3.5.3
        version: 3.5.3
      typescript:
        specifier: 5.8.3
        version: 5.8.3
      vite:
        specifier: 6.3.5
        version: 6.3.5(@types/node@22.15.18)
      vitest:
        specifier: 3.1.3
        version: 3.1.3(@types/node@22.15.18)
      vue-tsc:
        specifier: 2.2.10
        version: 2.2.10(typescript@5.8.3)

packages:

  '@babel/helper-string-parser@7.29.7':
    resolution: {integrity: sha512-Pb5ijPrZ89GDH8223L4UP8i6QApWxs04RbPQJTeWDV0/keR2E36MeKnyr6LYmUUvqRRI+Iv87SuF1W6ErINzYw==}
    engines: {node: '>=6.9.0'}

  '@babel/helper-validator-identifier@7.29.7':
    resolution: {integrity: sha512-qehxGkRj55h/ff8EMaJ+cYhyaKlHIxqYDn682wQD7RNp9UujOQsHog2uS0r2vzr4pW+sXf90NeeayjcNaX3fFg==}
    engines: {node: '>=6.9.0'}

  '@babel/parser@7.29.9':
    resolution: {integrity: sha512-CjXrNHTnvqBVqHgdBysY3vk2T8tpJHb5/RMeHJBTyVa9xgugCB0CJTx/3oO8RV2QRQP391RWpB7D6hLjm8V9uA==}
    engines: {node: '>=6.0.0'}
    hasBin: true

  '@babel/types@7.29.8':
    resolution: {integrity: sha512-Vj1jF3cPfxg7OAfoI7QnVKLoILlm2JF9pnVHrX8qx7AHMiYWT+NDAA7jChlNgRS4WTLc/fD1lXLmPixluj+3Gg==}
    engines: {node: '>=6.9.0'}

  '@capacitor/android@7.2.0':
    resolution: {integrity: sha512-zdhEy3jZPG5Toe/pGzKtDgIiBGywjaoEuQWnGVjBYPlSAEUtAhpZ2At7V0SCb26yluAuzrAUV0Ue+LQeEtHwFQ==}
    peerDependencies:
      '@capacitor/core': ^7.2.0

  '@capacitor/app@7.0.1':
    resolution: {integrity: sha512-ArlVZAAla4MwQoKh26x2AaTDOBh5Vhp1VhMKR3RwqZSsZnazKTFGNrPbr9Ez5r1knnEDfApyjwp1uZnXK1WTYQ==}
    peerDependencies:
      '@capacitor/core': '>=7.0.0'

  '@capacitor/cli@7.2.0':
    resolution: {integrity: sha512-RNW9vtYYYSDmOdguYBSW0VpRnG/d6lGydlc9DLrJ7qbSPxFrotTz9IjkM48O+SruUma61DyuSqJttdbay2xSxg==}
    engines: {node: '>=20.0.0'}
    hasBin: true

  '@capacitor/core@7.2.0':
    resolution: {integrity: sha512-2zCnA6RJeZ9ec4470o8QMZEQTWpekw9FNoqm5TLc10jeCrhvHVI8MPgxdZVc3mOdFlyieYu4AS1fNxSqbS57Pw==}

  '@capacitor/ios@7.2.0':
    resolution: {integrity: sha512-MQgRZcXZpbpjN83bjkGrzQd7s3XeHBZplmWf38/msF/siMGJKLrXNmNzmmPIWA5Xpi/aH6UoJFk1wXuU2U+zMg==}
    peerDependencies:
      '@capacitor/core': ^7.2.0

  '@esbuild/aix-ppc64@0.25.12':
    resolution: {integrity: sha512-Hhmwd6CInZ3dwpuGTF8fJG6yoWmsToE+vYgD4nytZVxcu1ulHpUQRAB1UJ8+N1Am3Mz4+xOByoQoSZf4D+CpkA==}
    engines: {node: '>=18'}
    cpu: [ppc64]
    os: [aix]

  '@esbuild/android-arm64@0.25.12':
    resolution: {integrity: sha512-6AAmLG7zwD1Z159jCKPvAxZd4y/VTO0VkprYy+3N2FtJ8+BQWFXU+OxARIwA46c5tdD9SsKGZ/1ocqBS/gAKHg==}
    engines: {node: '>=18'}
    cpu: [arm64]
    os: [android]

  '@esbuild/android-arm@0.25.12':
    resolution: {integrity: sha512-VJ+sKvNA/GE7Ccacc9Cha7bpS8nyzVv0jdVgwNDaR4gDMC/2TTRc33Ip8qrNYUcpkOHUT5OZ0bUcNNVZQ9RLlg==}
    engines: {node: '>=18'}
    cpu: [arm]
    os: [android]

  '@esbuild/android-x64@0.25.12':
    resolution: {integrity: sha512-5jbb+2hhDHx5phYR2By8GTWEzn6I9UqR11Kwf22iKbNpYrsmRB18aX/9ivc5cabcUiAT/wM+YIZ6SG9QO6a8kg==}
    engines: {node: '>=18'}
    cpu: [x64]
    os: [android]

  '@esbuild/darwin-arm64@0.25.12':
    resolution: {integrity: sha512-N3zl+lxHCifgIlcMUP5016ESkeQjLj/959RxxNYIthIg+CQHInujFuXeWbWMgnTo4cp5XVHqFPmpyu9J65C1Yg==}
    engines: {node: '>=18'}
    cpu: [arm64]
    os: [darwin]

  '@esbuild/darwin-x64@0.25.12':
    resolution: {integrity: sha512-HQ9ka4Kx21qHXwtlTUVbKJOAnmG1ipXhdWTmNXiPzPfWKpXqASVcWdnf2bnL73wgjNrFXAa3yYvBSd9pzfEIpA==}
    engines: {node: '>=18'}
    cpu: [x64]
    os: [darwin]

  '@esbuild/freebsd-arm64@0.25.12':
    resolution: {integrity: sha512-gA0Bx759+7Jve03K1S0vkOu5Lg/85dou3EseOGUes8flVOGxbhDDh/iZaoek11Y8mtyKPGF3vP8XhnkDEAmzeg==}
    engines: {node: '>=18'}
    cpu: [arm64]
    os: [freebsd]

  '@esbuild/freebsd-x64@0.25.12':
    resolution: {integrity: sha512-TGbO26Yw2xsHzxtbVFGEXBFH0FRAP7gtcPE7P5yP7wGy7cXK2oO7RyOhL5NLiqTlBh47XhmIUXuGciXEqYFfBQ==}
    engines: {node: '>=18'}
    cpu: [x64]
    os: [freebsd]
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

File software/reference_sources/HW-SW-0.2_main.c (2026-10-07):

#include "peripherals.h"
#include "board.h"
#include "mori_core.h"
#include "sdkconfig.h"
#include "esp_timer.h"
#include "esp_task_wdt.h"
#include "driver/uart.h"
#include "freertos/FreeRTOS.h"
#include "freertos/task.h"
#include "freertos/queue.h"
#include <stdio.h>
#include <string.h>
#include <math.h>
static TaskHandle_t control_handle;static QueueHandle_t commands,logs;
static portMUX_TYPE mux=portMUX_INITIALIZER_UNLOCKED;
static volatile uint64_t imu_edge_us;static volatile unsigned irq_fault;
static bool peripherals_ok;
typedef struct{mori_command_t cmd;bool head;float angle;} app_command_t;
typedef struct{uint64_t us;int state,fault;float angle,v,battery,current,tl,tr,ul,ur;uint32_t run_us,latency_us,max_run_us,max_latency_us,period_jitter_us,max_jitter_us,dropped;bool command_rejected;int cal_count;} log_t;
static void IRAM_ATTR data_ready(void*arg){(void)arg;uint64_t now=esp_timer_get_time();portENTER_CRITICAL_ISR(&mux);imu_edge_us=now;portEXIT_CRITICAL_ISR(&mux);BaseType_t w=pdFALSE;if(control_handle)vTaskNotifyGiveFromISR(control_handle,&w);if(w)portYIELD_FROM_ISR();}
static void IRAM_ATTR fault_edge(void*arg){(void)arg;gpio_set_level(PIN_ARM,0);portENTER_CRITICAL_ISR(&mux);irq_fault=1;portEXIT_CRITICAL_ISR(&mux);}
static float limit(float v,float lo,float hi){return fminf(hi,fmaxf(lo,v));}
static void control_task(void*arg){
 (void)arg;mori_t m;mori_config_t cfg={0};
#ifdef CONFIG_MORI_POWER_STAGE_VERIFIED
 cfg.power_verified=true;
#endif
#ifdef CONFIG_MORI_ENABLE_BALANCE
 cfg.balance_enabled=true;
#endif
 mori_init(&m,cfg);mori_sample_t s={0};
 ESP_ERROR_CHECK(esp_task_wdt_add(NULL));
 uint64_t last=esp_timer_get_time();uint32_t max_run=0,max_latency=0,max_jitter=0,dropped=0;unsigned frame=0;bool heartbeat=false,head_active=false;
 float head_target=0,head_position=0,head_velocity=0;
 while(1){
  uint32_t events=ulTaskNotifyTake(pdTRUE,pdMS_TO_TICKS(8));uint64_t begin=esp_timer_get_time(),edge;
  portENTER_CRITICAL(&mux);edge=imu_edge_us;unsigned irq=irq_fault;irq_fault=0;portEXIT_CRITICAL(&mux);
  float dt=(begin-last)*1e-6f;uint64_t period=begin-last;last=begin;
  s.now_us=begin;s.imu_us=edge;
  s.driver_ok=gpio_get_level(PIN_FAULT);s.estop_ok=gpio_get_level(PIN_ESTOP);
  if(irq&&(m.state==MORI_BENCH||m.state==MORI_BALANCE))mori_trip(&m,s.estop_ok?MF_DRIVER:MF_ESTOP);
  s.imu_ok=peripherals_ok&&events==1&&imu_read(&s)==ESP_OK;
  if(events>1)dropped+=events-1;
  s.encoders_ok=encoders_read(&s.v_left,&s.v_right,dt);
  if(frame%8==0){s.monitor_ok=peripherals_ok&&monitors_read(&s)==ESP_OK;}
  /* The monitoring timestamp can be later than begin. Use completion time for freshness,
     while retaining actual DRDY timestamp to measure scheduling and bus latency. */
  s.now_us=esp_timer_get_time();
  mori_output_t out=mori_step(&m,&s);
  bool rejected=false;app_command_t ac; /* commands only after current health sample */
  for(int k=0;k<2&&xQueueReceive(commands,&ac,0)==pdTRUE;k++){
   if(ac.head){
#ifndef CONFIG_MORI_HEAD_VERIFIED
    rejected=true;
#else
    if(m.state==MORI_FAULT||m.state==MORI_CALIBRATING||!s.estop_ok||!s.monitor_ok||!isfinite(ac.angle)||fabsf(ac.angle)>50)rejected=true;
    else{head_target=ac.angle;head_active=true;}
#endif
   }else if(!mori_command(&m,ac.cmd))rejected=true;
  }
  /* Re-read state after commands. Arming begins on next healthy sample; disarming is immediate. */
  if(m.state!=MORI_BALANCE&&m.state!=MORI_BENCH)out.enable=false;
  if(m.state==MORI_FAULT||!s.estop_ok){head_disable();head_active=false;}
  if(head_active&&frame%8==0){
   float hd=8.0f/416,desired_v=limit((head_target-head_position)*2,-30,30);
   head_velocity+=limit(desired_v-head_velocity,-60*hd,60*hd);head_position=limit(head_position+head_velocity*hd,-50,50);head_set(head_position);
  }
  uint32_t runtime=esp_timer_get_time()-begin;
  if(runtime>2404&&(m.state==MORI_BALANCE||m.state==MORI_BENCH)){mori_trip(&m,MF_TIMING);out.enable=false;}
  motor_apply(out);
  runtime=esp_timer_get_time()-begin;
  if(runtime>2404&&(m.state==MORI_BALANCE||m.state==MORI_BENCH)){mori_trip(&m,MF_TIMING);motor_disable();out.enable=false;}
  if(s.imu_ok&&s.monitor_ok&&s.encoders_ok&&s.estop_ok&&s.driver_ok&&runtime<=2404){heartbeat=!heartbeat;gpio_set_level(PIN_HEARTBEAT,heartbeat);}
  else gpio_set_level(PIN_ARM,0);
  esp_task_wdt_reset();
  runtime=esp_timer_get_time()-begin;uint32_t latency=(edge<=begin)?begin-edge:0;
  uint32_t jitter=(period>2404)?period-2404:2404-period;
  if(runtime>max_run){max_run=runtime;}
  if(latency>max_latency){max_latency=latency;}
  if(jitter>max_jitter){max_jitter=jitter;}
  if(frame%80==0||rejected||m.state==MORI_FAULT){log_t l={.us=begin,.state=m.state,.fault=m.fault,.angle=m.theta,.v=(s.v_left+s.v_right)/2,.battery=s.battery_v,.current=s.bus_a,.tl=s.temp_left_c,.tr=s.temp_right_c,.ul=out.enable?out.left:0,.ur=out.enable?out.right:0,.run_us=runtime,.latency_us=latency,.max_run_us=max_run,.max_latency_us=max_latency,.period_jitter_us=jitter,.max_jitter_us=max_jitter,.dropped=dropped,.command_rejected=rejected,.cal_count=m.calibration_count};xQueueOverwrite(logs,&l);}
  frame++;
 }
}
static void logging_task(void*arg){(void)arg;log_t l;puts("us,state,fault,pitch_rad,v_m_s,bat_V,motor_bus_A,TL_C,TR_C,uL,uR,run_us,wake_us,max_run_us,max_wake_us,jitter_us,max_jitter_us,dropped,rejected,cal_count");while(1)if(xQueueReceive(logs,&l,portMAX_DELAY))printf("%llu,%s,%d,%.5f,%.4f,%.3f,%.4f,%.1f,%.1f,%.4f,%.4f,%u,%u,%u,%u,%u,%u,%u,%d,%d\n",(unsigned long long)l.us,mori_state_name(l.state),l.fault,l.angle,l.v,l.battery,l.current,l.tl,l.tr,l.ul,l.ur,(unsigned)l.run_us,(unsigned)l.latency_us,(unsigned)l.max_run_us,(unsigned)l.max_latency_us,(unsigned)l.period_jitter_us,(unsigned)l.max_jitter_us,(unsigned)l.dropped,l.command_rejected,l.cal_count);}
static void parse_line(char*line){
 app_command_t c={0};bool valid=true;
 if(!strcmp(line,"calibrate"))c.cmd.type=MC_CALIBRATE;
 else if(!strcmp(line,"ack"))c.cmd.type=MC_ACK;
 else if(!strcmp(line,"arm bench"))c.cmd.type=MC_ARM_BENCH;
 else if(!strcmp(line,"arm balance"))c.cmd.type=MC_ARM_BALANCE;
 else if(!strcmp(line,"confirm_signs"))c.cmd.type=MC_CONFIRM_SIGNS;
 else if(!strcmp(line,"stop"))c.cmd.type=MC_STOP;
 else if(!strcmp(line,"disarm"))c.cmd.type=MC_DISARM;
 else if(sscanf(line,"duty %f %f",&c.cmd.a,&c.cmd.b)==2)c.cmd.type=MC_BENCH_DUTY;
 else if(sscanf(line,"move %f %f",&c.cmd.a,&c.cmd.b)==2)c.cmd.type=MC_MOVE;
 else if(sscanf(line,"gains %f %f %f %f",&c.cmd.a,&c.cmd.b,&c.cmd.c,&c.cmd.d)==4)c.cmd.type=MC_GAINS;
 else if(sscanf(line,"head %f",&c.angle)==1)c.head=true;
 else valid=false;
 if(!valid)puts("REJECT syntax; calibrate | arm bench | duty L R | confirm_signs | gains kp kd kv ki | arm balance | move m/s yaw_duty | stop | disarm | ack | head deg");
 else if(xQueueSend(commands,&c,0)!=pdTRUE)puts("REJECT command queue full");
}
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

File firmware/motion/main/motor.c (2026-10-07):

#include "peripherals.h"
#include "board.h"
#include "mount_config.h"
#include "mori_ui.h"
#include "driver/ledc.h"
#include "esp_timer.h"
#include "sdkconfig.h"
#include <math.h>
static const mori_mount_t mount=MORI_MOUNT_INITIALIZER;
static bool io_ok=true;
static bool enabled;static int64_t wake;
void motor_disable(void){
 gpio_set_level(PIN_ARM,0);enabled=false;
 for(int i=0;i<4;i++)if(ledc_set_duty_and_update(LEDC_LOW_SPEED_MODE,i,0,0)!=ESP_OK)io_ok=false;
}
void motor_init(void){
 gpio_config_t g={.pin_bit_mask=(1ULL<<PIN_ARM)|(1ULL<<PIN_HEARTBEAT),.mode=GPIO_MODE_OUTPUT,.pull_down_en=true};ESP_ERROR_CHECK(gpio_config(&g));
 gpio_set_level(PIN_ARM,0);gpio_set_level(PIN_HEARTBEAT,0);
 ledc_timer_config_t t={.speed_mode=LEDC_LOW_SPEED_MODE,.duty_resolution=LEDC_TIMER_10_BIT,.timer_num=LEDC_TIMER_0,.freq_hz=20000,.clk_cfg=LEDC_AUTO_CLK};ESP_ERROR_CHECK(ledc_timer_config(&t));
 int pins[]={PIN_AIN1,PIN_AIN2,PIN_BIN1,PIN_BIN2};
 for(int i=0;i<4;i++){ledc_channel_config_t c={.gpio_num=pins[i],.speed_mode=LEDC_LOW_SPEED_MODE,.channel=i,.timer_sel=LEDC_TIMER_0,.duty=0};ESP_ERROR_CHECK(ledc_channel_config(&c));}
 ESP_ERROR_CHECK(ledc_fade_func_install(0)); /* required by IDF synchronous duty API */
 motor_disable(); /* preallocate per-channel synchronization while ARM is low */
}
static bool set_pair(int base,float duty){
 duty=fminf(.65f,fmaxf(-.65f,duty));uint32_t d=(uint32_t)(fabsf(duty)*1023);
 /* Set the previously active input low first; never momentarily assert both. */
 if(ledc_set_duty_and_update(LEDC_LOW_SPEED_MODE,base,0,0)!=ESP_OK)return false;
 if(ledc_set_duty_and_update(LEDC_LOW_SPEED_MODE,base+1,0,0)!=ESP_OK)return false;
 return !d||ledc_set_duty_and_update(LEDC_LOW_SPEED_MODE,base+(duty<0),d,0)==ESP_OK;
}
void motor_apply(mori_output_t o){
#ifndef CONFIG_MORI_POWER_STAGE_VERIFIED
 (void)o;motor_disable();return;
#endif
 if(!io_ok||!o.enable||!isfinite(o.left)||!isfinite(o.right)||!gpio_get_level(PIN_FAULT)||!gpio_get_level(PIN_ESTOP)){motor_disable();return;}
 if(!enabled){gpio_set_level(PIN_ARM,1);enabled=true;wake=esp_timer_get_time()+2000;}
 if(esp_timer_get_time()<wake)return; /* driver requires up to 1ms after nSLEEP */
 if(!set_pair(0,o.left*mount.motor_sign[0])||!set_pair(2,o.right*mount.motor_sign[1])){io_ok=false;motor_disable();}
}
static bool head_started;
void head_init(void){
 ledc_timer_config_t t={.speed_mode=LEDC_LOW_SPEED_MODE,.duty_resolution=LEDC_TIMER_14_BIT,.timer_num=LEDC_TIMER_1,.freq_hz=50,.clk_cfg=LEDC_AUTO_CLK};ESP_ERROR_CHECK(ledc_timer_config(&t));
 ledc_channel_config_t c={.gpio_num=PIN_HEAD,.speed_mode=LEDC_LOW_SPEED_MODE,.channel=LEDC_CHANNEL_4,.timer_sel=LEDC_TIMER_1,.duty=0};ESP_ERROR_CHECK(ledc_channel_config(&c));head_started=true;head_disable();
}
bool head_set(float deg){
#ifndef CONFIG_MORI_HEAD_VERIFIED
 (void)deg;return false;
#else
 if(!head_started||!isfinite(deg)||fabsf(deg)>50)return false; /* ±60 design, ±50 commissioning */
 /* SER0037 nominal 270deg/2000us; head gear radii 8:14.
    External gears reverse direction: sign must be measured before enabling. */
 float us=mori_head_pulse_us(deg);
 return ledc_set_duty_and_update(LEDC_LOW_SPEED_MODE,LEDC_CHANNEL_4,(uint32_t)(us/20000*16383),0)==ESP_OK;
#endif
}
void head_disable(void){if(head_started)ledc_set_duty_and_update(LEDC_LOW_SPEED_MODE,LEDC_CHANNEL_4,0,0);}

bool motor_io_ok(void){return io_ok;}

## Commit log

2026-10-07 archive: add received hardware contracts and wiring
    [01_端口总表.csv, 02_端口逐针定义.csv, 03_逐针接线表.csv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]
2026-10-07 archive: add firmware and software verification tools
    [partitions.csv, pinmap.csv, wiring.csv]
2026-10-07 archive: add four current native KiCad projects
    [MORI_imu_P5R4.kicad_pcb, MORI_imu_P5R4.kicad_sch, MORI_motion_P5R7.kicad_pcb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]
2026-10-07 archive: add current mechanical construction pipeline
2026-10-07 archive: add current geometry and mechanical handoff
2026-10-07 archive: add current Blender, STL and animation assets
    [Battery_Tray.stl, Body_Front.stl, Body_Rear.stl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]
2026-10-07 docs: add current navigation and verified archive restore utility
2026-10-07 archive: package large native PCB and footprint geometry losslessly
    [MORI_imu_P5R4.kicad_pcb, MORI_motion_P5R7.kicad_pcb, MORI_power_P5R6.kicad_pcb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]
2026-10-07 Fix review findings across software and prototype archive delivery
    [04_线束汇总.csv, 06_屏幕FFC待核对.csv, Display_Frame.stl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]
2026-10-07 Fix follow-up review cases and validate current delivery evidence
2026-10-07 Preserve tracking consent and reject invalid saved authentication
    [Wheel_Axle_Common_DESIGN_REFERENCE.step, Wheel_Spacer_10mm_DESIGN_REFERENCE.step, Wheel_Spacer_4.5mm_DESIGN_REFERENCE.step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]
2026-10-08 Sync M1.54 mechanical models and assembly animation
    [Wheel_Axle_Common_DESIGN_REFERENCE.step, Wheel_Spacer_10mm_DESIGN_REFERENCE.step, Wheel_Spacer_4.5mm_DESIGN_REFERENCE.step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]
2026-10-10 Publish M1.55 models and pre-arrival evidence
    [Pitch_Yoke.stl, Wheel_Axle_Common_DESIGN_REFERENCE.step, Wheel_Spacer_10mm_DESIGN_REFERENCE.step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]
2026-10-10 fix: close M1.55 review findings and refresh delivery evidence
    [Wheel_Axle_Common_DESIGN_REFERENCE.step, Wheel_Spacer_10mm_DESIGN_REFERENCE.step, Wheel_Spacer_4.5mm_DESIGN_REFERENCE.step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]
2026-10-17 Archive two-wheel feasibility rig with models, wiring and verified evidence
2026-10-25 chore: organize MORI 1.3 snapshot and fix portable mechanical checks (#15)
    Unify current project entries, publish M1.58/C3 R98I source snapshots and shelled README views. Fix repeated metadata finalization, current UPS-control animation assignments, and portable saved-model validation inputs.
    Latest reviewed head: d488c073ce7f5a0be6449d09bd406a7e1b2b01f8. Project snapshot CI and 31 tool regressions passed; review completed without findings. Engineering BLOCKED/NOT_TESTED states remain explicit; no manufacturing release.
2026-10-25 hardware: 同步 C3 R108P 原型工程与审查记录 (#16)
2026-10-25 chore: 分开正式机器人与验证车，统一当前入口和版本记录 (#17)
2026-10-29 hardware: publish C3 R188C progress and R190 study snapshot (#19)
    Publish the independent R188C development board and frozen studies through R190 in one progress snapshot. Preserve R108P, mechanical/software/test-rig sources and the unqualified engineering status.
    Native readback, source and archive integrity review, offline checks and publication CI passed within their documented scope. Nineteen connections and full engineering qualification remain incomplete.
